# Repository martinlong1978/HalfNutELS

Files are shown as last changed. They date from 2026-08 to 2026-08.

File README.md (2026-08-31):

# HalfNutELS — Electronic Leadscrew

An open-source **Electronic Leadscrew (ELS)** controller for a metalworking lathe, running on an
**ESP32-WROOM-32E**, with a 320×240 LVGL TFT interface, a 3×3 keypad and a rotary encoder.

An electronic leadscrew replaces a lathe's mechanical change gears / gearbox. Instead of a train of
gears mechanically coupling the spindle to the leadscrew, an **encoder** on the spindle is read by
the microcontroller, which drives a **stepper motor** on the leadscrew in software-defined ratio to
the spindle. This lets you select any thread pitch or feed rate electronically — for single-point
threading and powered feeding — without swapping gears.

> **Note on the name:** *half-nuts* are the split nut a lathe operator clamps onto the leadscrew to
> engage a threading pass — and the part an electronic leadscrew makes redundant, since the pitch is
> now held in software rather than caught on a thread-dial line. The project was called *TeensyELS*
> until August 2026, after the Teensy it began on; Teensy support was removed well before the rename,
> and naming firmware after its microcontroller was a poor idea in the first place. The upstream
> project it derives from is still called TeensyELS — see [Attribution](#attribution). The KiCad
> projects and the board silkscreen also still carry the old name.

> **Note on the hardware:** the current design is the **LVGL board** in
> [`kicad/LVGL/`](kicad/LVGL/) (silkscreened `TeensyELS v0.6`, pre-rename) — an ESP32-WROOM-32E
> soldered directly to the board, driving a 320×240 SPI TFT through LVGL. It is the only board design
> in the repository — the earlier revisions have been removed.

---

## Contents
- [Features](#features)
- [Hardware / Components](#hardware--components)
- [Enclosure & keycaps](#enclosure--keycaps)
- [Getting boards made (PCB)](#getting-boards-made-pcb)
- [Building & flashing the firmware](#building--flashing-the-firmware)
- [Connecting & configuring](#connecting--configuring)
- [Operating the ELS — controls & display](#operating-the-els--controls--display)
- [Cutting a thread](#cutting-a-thread)
- [Firmware updates](#firmware-updates)
- [Settings reference](#settings-reference)
- [Diagnostics](#diagnostics)
- [Testing / development](#testing--development)
- [License](#license)
- [Attribution](#attribution)
- [Safety disclaimer](#safety-disclaimer)

---

## Features

- **Threading** — synchronise the leadscrew to the spindle at a selectable thread pitch for
  single-point threading. Metric (mm/rev) and imperial (TPI) thread pitch tables are built in.
- **Reverse threading** — a thread mode that runs the carriage in the opposite direction (from the
  left stop toward the right) for left-hand threads or threading away from a shoulder.
- **Feeding** — powered feed at a selectable feed rate (mm/rev metric, or thou/rev imperial).
- **Feed / thread mode switching** from the panel; **metric / imperial** from the menu.
- **Jog** — move the carriage left/right under power. Supports both an interactive "hold to jog"
  mode and a "jog to stop" mode.
- **End stops / stop positions** — set left and right stop positions so the carriage automatically
  decelerates and stops at a repeatable point (useful for threading up to a shoulder).
- **Thread sync** — the leadscrew tracks the spindle's angular position so a partially cut thread can
  be picked up again on the next pass.
- **Motion lockout** — while the carriage is under power the panel answers only **HALT** and
  **ENABLE**. There is no lock key to remember: the machine locks itself exactly when it matters.
  (This replaced an explicit button lock, which had to be unlocked at every power-on.)
- **DRO** — carriage position referenced to an endstop, with a travel bar that doubles as a readout.
- **Dark and light themes**, selectable on the device.
- **Web-based configuration** — all lathe parameters (encoder PPR, stepper PPR, gearbox ratio,
  leadscrew pitch, speeds, acceleration) plus WiFi credentials are configured over a built-in web
  page; settings are stored in the ESP32's non-volatile flash.
- **Over-the-air (OTA) firmware update** — pulls the latest [GitHub release](https://github.com/martinlong1978/HalfNutELS/releases)
  from a stable permalink and skips the download if the device is already on that version.
- **Motion-trace capture** — records ~25 s of following error, loop timing and spindle deltas and
  uploads it as CSV for offline analysis. Built to diagnose a threading glitch; kept because it is
  the fastest way to answer "is the fault in the maths or in the timing?".
- **On-device display** — a 240×320 ST7789 SPI TFT, driven in landscape (**320×240**) via **LVGL**,
  shows current mode, pitch, spindle RPM and status.
- **Rotary encoder** — turns to adjust whatever the panel currently has focused; its
  built-in LED shows the run state at a glance (the firmware drives the red and green channels,
  alternating them to flash a two-colour status).

---

## Hardware / Components

The controller is built around a custom PCB. KiCad design files, gerbers and fabrication outputs are
in the [`kicad/`](kicad/) directory.

**The current design is [`kicad/LVGL/`](kicad/LVGL/)** — silkscreened *TeensyELS v0.6*, a **4-layer**
board of roughly **113 × 109 mm**. It does not socket a dev-board module: the **ESP32-WROOM-32E is
soldered directly to the PCB**, the display is a separate SPI TFT module on a 14-pin socket, and the
board is designed to be **SMT-assembled** (JLCPCB) with only the connectors and the rotary encoder
hand-soldered.

### Bill of materials

**SMT parts** — taken from the JLCPCB production BOM
([`kicad/LVGL/jlcpcb/production_files/BOM-TeensyELS.csv`](kicad/LVGL/jlcpcb/production_files/BOM-TeensyELS.csv)),
cross-checked against the schematic:

| Designator(s) | Qty | Part / Value | Footprint | LCSC |
|---|---|---|---|---|
| U2 | 1 | **ESP32-WROOM-32E** — main controller (Wi-Fi module, 4 MB flash) | ESP32-WROOM-32D | C701342 |
| U1 | 1 | AMS1117-3.3 — 5 V → 3.3 V regulator | SOT-223-3 | C6186 |
| Q2–Q7, Q9 | 7 | BSS138 N-channel MOSFET (3.3 V ↔ 5 V level shifting, LED drive) | SOT-23 | C7420339 |
| C1 | 1 | 10 µF capacitor | 0805 | C15850 |
| C2 | 1 | 22 µF capacitor | 0805 | C45783 |
| C3, C4 | 2 | 0.1 µF capacitor | 0805 | C49678 |
| R1–R8, R11, R12, R17, R18, R20, R21 | 14 | 10 kΩ resistor (pull-ups) | 0805 | C17414 |
| R9, R10, R19 | 3 | 330 Ω resistor (encoder LED series) | 0805 | C17630 |
| R13, R14 | 2 | 0 Ω link (encoder direct-connect option) | 0805 | C17477 |
| SW1–SW10 | 10 | Omron B3FS-101xP **SMD** tactile switch (SW2–SW10 = the 3×3 keypad; SW1 = stepper-enable override) | SW_SPST_Omron_B3FS-101xP | C231324 |
| J5 | 1 | 2×3 1.27 mm header — UART programming header | PinHeader 2x03 1.27 mm SMD | C42372553 |

**Not fitted (DNP)** — an alternative encoder input path, see the note below:

| Designator(s) | Qty | Part / Value |
|---|---|---|
| Q1, Q8 | 2 | BSS138 (encoder level-shift MOSFETs) |
| R15, R16 | 2 | 1 kΩ (gate resistors for Q1/Q8) |

**Through-hole / hand-soldered parts** — these are *not* in the assembly BOM and must be fitted
yourself:

| Designator | Qty | Part | Purpose |
|---|---|---|---|
| J1 | 1 | Shielded RJ45 jack (RCH RC01937) | **Stepper driver** — step / dir / enable / alarm, at 5 V |
| J2 | 1 | JST-XH 4-pin vertical header (B4B-XH-A) | **Spindle encoder** — 5 V, GND, A, B |
| J3 | 1 | 1×14 2.54 mm socket | **Display module** (see below) |
| J4 | 1 | 2-pin 5.08 mm screw terminal (CUI TB007-508-02) | **5 V power input** |
| E1 | 1 | Illuminated (RGB) rotary encoder, SparkFun footprint | Pitch / jog-rate selection + status LED |

Not on the board at all, but **required to build a working ELS**:

- A **240×320 SPI TFT module** with the common **14-pin 2.54 mm header** (9 display pins + 5 touch
  pins). The firmware drives it as an **ST7789** and uses it in landscape, 320×240. Only the display
  pins are wired — the 5 touch pins are unconnected, and the backlight pin is tied to +3.3 V, so the
  backlight is permanently on and is *not* under software control.
- A **spindle encoder** — a quadrature encoder on the lathe spindle, wired to **J2** (not J1). The
  default configuration assumes **1200 PPR** (see [Settings reference](#settings-reference)).
- A **stepper motor + driver** for the leadscrew, wired to the RJ45 jack **J1**. The board provides
  step, dir and enable as 5 V open-drain outputs (10 kΩ pull-ups to +5 V) and accepts the driver's
  alarm output. The default configuration assumes a **400 step/rev** stepper.
- A **5 V supply** into J4 (which also feeds the encoder and the 3.3 V regulator), plus a suitable
  **power supply for the stepper driver** itself.
- A **USB-to-serial adapter** for flashing — the board has no USB connector, see
  [Building & flashing](#building--flashing-the-firmware).

> **Encoder input — 3.3 V vs 5 V.** J2's A/B pins can reach the ESP32 two ways: directly through the
> 0 Ω links **R13/R14**, or level-shifted through **Q1/Q8 + R15/R16**. The assembly BOM fits the 0 Ω
> links and leaves the MOSFET path off, i.e. it expects an encoder whose outputs are safe to feed
> straight into a 3.3 V GPIO. If your encoder swings to 5 V, fit Q1/Q8 and R15/R16 and leave R13/R14
> off. **Please verify against the schematic** ([`kicad/LVGL/TeensyELS.kicad_sch`](kicad/LVGL/TeensyELS.kicad_sch))
> before ordering.

### Connectors

| Ref | Type | Pinout |
|---|---|---|
| **J4** | 2-pin screw terminal | 1 = GND, 2 = **+5 V in** |
| **J2** | JST-XH 4-pin | 1 = +5 V, 2 = GND, 3 = encoder B, 4 = encoder A |
| **J1** | RJ45 (shielded) | 1 = ALARM (in), 3 = ENABLE, 5 = DIR, 7 = STEP; 2/4/6/8 = GND; shield = GND. All 5 V. |
| **J3** | 1×14 socket (display) | 14 = VCC, 13 = GND, 12 = CS, 11 = RESET, 10 = DC, 9 = MOSI, 8 = SCK, 7 = LED (tied to +3.3 V), 6 = MISO (not connected to the ESP32); 5–1 = touch pins, unconnected |
| **J5** | 2×3 1.27 mm | 1 = EN, 2 = +3.3 V, 3 = TXD, 4 = GND, 5 = RXD, 6 = BOOT (GPIO0) |
| **SW1** | on-board push button | Pulls the stepper **ENABLE** line to +5 V — a manual override, independent of the firmware |

### Pin assignments (ESP32)

Defined in [`lib/config/board.h`](lib/config/board.h) and matching the LVGL schematic:

| Function | GPIO |
|---|---|
| Spindle encoder A / B (J2) | 35 / 34 |
| UI rotary encoder A / B (E1) | 39 / 36 |
| Encoder status LED — red / green / blue (E1) | 22 / 21 / 12 |
| Leadscrew step | 25 |
| Leadscrew direction | 26 |
| Stepper enable | 17 |
| Stepper driver alarm input | 27 *(wired on the board; not read by the current firmware)* |
| Keypad matrix rows (H1/H2/H3) | 32 / 33 / 2 |
| Keypad matrix columns (V1/V2/V3) | 13 / 14 / 15 |
| TFT display (MOSI/SCLK/CS/DC/RST) | 19 / 18 / 5 / 16 / 23 |
| TFT backlight (`TFT_BL`) | 4 *(defined in the build flags but **not connected** on this board)* |
| Programming UART TXD / RXD (J5) | 1 / 3 |

> The A/B pins of both encoders are swapped in `board.h` relative to the schematic net names — that
> only sets which way round the counting goes, and is deliberate.

> **The keypad matrix is polled, not interrupt-driven.** A 2 ms task scans it and a host-tested
> debounce ([`lib/keyscan/`](lib/keyscan/)) turns the readings into press / click / hold / release
> events. Edge interrupts were tried and removed — see [`docs/keypad-audit.md`](docs/keypad-audit.md)
> for why they cannot be made reliable here.

---

## Enclosure & keycaps

Two 3D models are provided in [`cad/`](cad/), both as **STEP** files:

| File | What it is |
|---|---|
| [`cad/Keycaps.step`](cad/Keycaps.step) | Keycaps for the 3×3 keypad |
| [`cad/Enclosure.step`](cad/Enclosure.step) | A full enclosure for the controller |

STEP is a neutral CAD interchange format — it imports into FreeCAD, Fusion and SolidWorks, so the
models can be measured and edited before you make anything from them. To 3D-print a part, convert it
to **STL** or **3MF** in your CAD tool and slice that; the same STEP file can go to a machine shop if
you would rather have the enclosure cut than printed.

The keycaps cover the nine keys of the panel keypad — which legend belongs on which cap is set out in
[Keypad layout](#keypad-layout), along with the warning to re-confirm the scan codes before making
caps if you have rewired the loom. For reference when checking fit, the board itself is roughly
**113 × 109 mm**.

> No print settings, material or fastener sizes are specified with these models. Check them against
> your own printer and hardware before committing to a run.

---

## Getting boards made (PCB)

Fabrication outputs for the LVGL board are pre-generated under [`kicad/LVGL/`](kicad/LVGL/). The
JLCPCB set in [`kicad/LVGL/jlcpcb/production_files/`](kicad/LVGL/jlcpcb/production_files/) is the one
to use — it is the only output that carries **LCSC part numbers**, and its BOM matches the assembly
intent (SMT parts only, encoder level-shift path left off).

> ⚠️ **Do not use `kicad/LVGL/production/bom.csv` or `positions.csv`.** Those files are stale
> carry-overs from an earlier board revision — they still list a socketed display module and a Teensy
> footprint, neither of which exists on this board. Regenerate them from KiCad if you need them.

### Option A — JLCPCB (bare board, or with assembly)

1. Go to [jlcpcb.com](https://jlcpcb.com) and click **Add gerber file**.
2. Upload [`kicad/LVGL/jlcpcb/production_files/GERBER-TeensyELS.zip`](kicad/LVGL/jlcpcb/production_files/GERBER-TeensyELS.zip)
   (do **not** unzip it — upload the zip directly). The KiCad-native export
   [`kicad/LVGL/gerbers.zip`](kicad/LVGL/gerbers.zip) is equivalent if you prefer it.
3. Confirm the auto-detected settings: **Layers = 4**, and the board dimensions shown in the preview
   (≈113 × 109 mm). Choose thickness, colour, surface finish, etc. as desired.
4. *(Optional — assembly / PCBA)* Enable **PCB Assembly** (top side only), then upload:
   - **BOM:** [`kicad/LVGL/jlcpcb/production_files/BOM-TeensyELS.csv`](kicad/LVGL/jlcpcb/production_files/BOM-TeensyELS.csv)
   - **Pick-and-place / CPL:** [`kicad/LVGL/jlcpcb/production_files/CPL-TeensyELS.csv`](kicad/LVGL/jlcpcb/production_files/CPL-TeensyELS.csv)
5. Review the placement in JLCPCB's assembly preview — pay particular attention to the orientation of
   U1, U2 and the MOSFETs — resolve any part substitutions, and place the order.
6. Hand-solder the through-hole parts afterwards: **J1, J2, J3, J4 and the rotary encoder E1**.

### Option B — PCBWay

1. Go to [pcbway.com](https://www.pcbway.com) and choose **Quick-order PCB → Add Gerber File**.
2. Upload [`kicad/LVGL/gerbers.zip`](kicad/LVGL/gerbers.zip).
3. Confirm layer count (**4**) and dimensions, pick your board options, and add to cart.
4. *(Optional — assembly)* Choose **Turnkey Assembly** and provide the BOM and pick-and-place files
   above. PCBWay does not use LCSC numbers directly, so expect to confirm equivalents for each line.

---

## Building & flashing the firmware

The firmware is a [PlatformIO](https://platformio.org/) project (see
[`platformio.ini`](platformio.ini)).

### 1. Install PlatformIO

Install the [PlatformIO IDE extension for VS Code](https://platformio.org/install/ide?install=vscode),
or the [PlatformIO Core CLI](https://docs.platformio.org/en/latest/core/installation/index.html).
PlatformIO will automatically download the ESP32 toolchain and the libraries listed in
`platformio.ini` on first build.

### 2. Connect a USB-to-serial adapter

The LVGL board has **no USB connector** — the ESP32-WROOM-32E is programmed through the 2×3 1.27 mm
header **J5**:

| J5 pin | Signal | Adapter |
|---|---|---|
| 1 | EN (reset) | RTS *(optional — for auto-reset)* |
| 2 | +3.3 V | — *(do not back-feed if the board is powered from J4)* |
| 3 | TXD (ESP32 → adapter) | RX |
| 4 | GND | GND |
| 5 | RXD (adapter → ESP32) | TX |
| 6 | BOOT (GPIO0) | DTR *(optional — for auto-bootloader)* |

Use a **3.3 V** adapter. If you only wire TX/RX/GND, you must put the module into the bootloader by
hand — hold GPIO0 low, pulse EN low and release it, then start the upload.

### 3. Build & upload

There are two ESP32 build environments:

- **`esp32dev_usb`** — build and flash over the serial adapter. This is the environment to use for
  normal development. Edit the `upload_port` in `platformio.ini` (default `COM14`) to match the port
  your adapter enumerates as.

  ```sh
  pio run -e esp32dev_usb -t upload
  ```

- **`esp32dev_publish`** — a release build that uses a custom upload command (`publish.cmd`) for
  producing/publishing an OTA image rather than a direct flash.

  ```sh
  pio run -e esp32dev_publish
  ```

Both ESP32 environments still declare `board = lilygo-t-display`. That is just a convenient 4 MB
ESP32-D0WD profile and is compatible with the WROOM-32E module — the display geometry that matters is
set explicitly in the build flags (`TFT_WIDTH=240`, `TFT_HEIGHT=320`, ST7789 driver, SPI pins), and a
custom 4 MB partition table (`my_4MB.csv`) is used.

---

## Connecting & configuring

Configuration is done over WiFi through a built-in web page — there is no need to recompile to
retune the firmware for your lathe.

1. **Enter configuration mode.** The device starts a WiFi **Access Point** on first boot (when no
   valid settings are stored yet), whenever you **hold `OK` — the centre key — while powering on**,
   or from the **Wi-Fi setup** menu tile. See [`src/main.cpp`](src/main.cpp).
   - AP SSID: **`ELS_Wifi`**
   - AP password: **`123456789`**
2. **Connect** your phone or laptop to that access point. The SSID, password and IP address are shown
   on the device's display, along with a QR code for the WiFi credentials.
3. **Open the device in a browser.** The firmware runs a **captive portal** — a catch-all DNS server
   plus the usual Android/Apple/Windows detection URLs — so most phones will pop the configuration
   page up automatically on connecting. If yours doesn't, browse to the IP shown on the display
   (typically `192.168.4.1`) to reach the *ELS Setup* page.

| First-run setup screen | Connected |
|---|---|
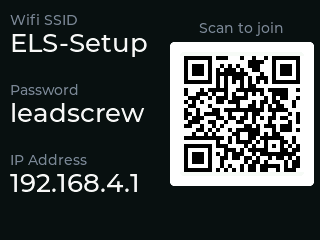
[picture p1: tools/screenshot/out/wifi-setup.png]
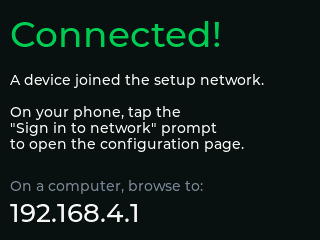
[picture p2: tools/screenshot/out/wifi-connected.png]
|  |  |

4. **Fill in the settings** (see [Settings reference](#settings-reference)) and press **Submit**.
   Settings are written to the ESP32's flash. Press **Reset** on the page (or power-cycle) to reboot
   into normal operation with the new settings.

---

## Operating the ELS — controls & display

The panel is nine keys and a rotary encoder. Everything below is driven from those.

> Every screenshot in this README is rendered from the **real display code** on a host machine
> (`bash tools/screenshot/render.sh`), so what you see here is what the panel draws.

### Power-on

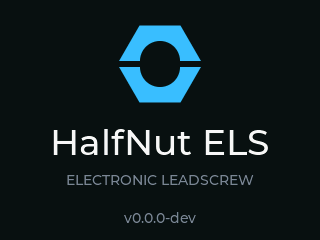
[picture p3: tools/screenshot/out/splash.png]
Boot splash


The splash holds for **two seconds** on every normal boot, then the rest screen replaces it. It
carries the running **firmware version**, which is the quickest way to check what a machine is on
without opening the menu — worth a glance after an over-the-air update. It is drawn on whichever
theme is stored, and it is skipped entirely on the first-run setup path, where the Wi-Fi credentials
matter more than the branding.

### The rest screen

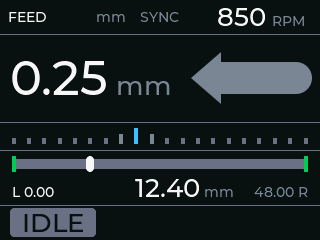
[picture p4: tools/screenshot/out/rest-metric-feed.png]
Rest screen, metric feed


Top row: **mode**, **units**, **sync state**, **spindle RPM**. The large figure is the current pitch
or feed rate. Below it the **travel bar** shows the carriage between the endstops — it doubles as a
DRO readout. The chip at the bottom left is the **machine state** (`IDLE`, `FEED`, `THREAD`, `JOG`).

| Metric thread | Imperial feed | Spindle running backwards |
|---|---|---|
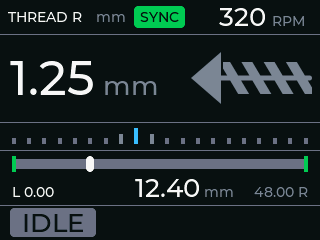
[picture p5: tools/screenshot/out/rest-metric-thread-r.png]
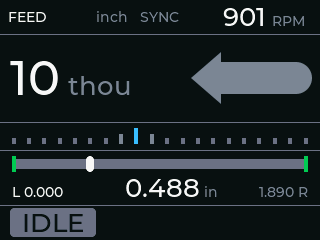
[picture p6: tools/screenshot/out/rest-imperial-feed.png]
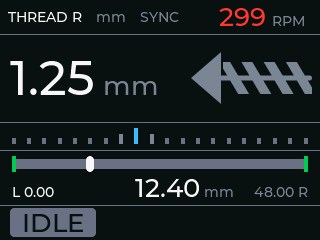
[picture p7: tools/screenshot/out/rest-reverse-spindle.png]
|  |  |  |

### Keypad layout

Selectors along the top, the two actuators plus `OK` in the middle where your thumbs sit, and
machine state along the bottom:

Mk2 keypad layout

| | Left | Centre | Right |
|---|---|---|---|
| **Top row** | `MODE` | `RATE` | `STOPS` |
| **Middle row** | `◀` | `OK` | `▶` |
| **Bottom row** | `HALT` | `MENU` | `ENABLE` |

The small numbers on the diagram are the **matrix scan codes** — useful when wiring a panel or
reading a debug trace. They are `code = H | V << 3`, with the H rows on GPIO 32 / 33 / 2 and the V
columns on GPIO 13 / 14 / 15; the mapping is defined in [`lib/config/board.h`](lib/config/board.h).
If you rewire the loom the nine codes stay distinct but the assignment transposes, so re-confirm by
pressing each key and reading its code before making new caps.

The three top keys choose **what the arrows drive**; the arrows are the only actuators. That is the
*focus model*: press a selector, a panel opens, the arrows adjust it, `OK` commits. Focus returns to
jog on its own after 4 seconds.

*(Holding `OK` during power-on boots into Wi-Fi configuration mode.)*

### Arrows at rest — jog

With nothing else focused the arrows move the carriage, and what they do depends on whether that
side has a stop set — the machine already knows which behaviour you mean:

| | Stop **set** on that side | Stop **unset** |
|---|---|---|
| **Click** | Run under power to the stop, then hold | — |
| **Hold** | (same as click) | Jog continuously while held; decelerate on release |

A second press of the same arrow during a powered run **cancels** it.

### Key reference

| Control | Click | Hold |
|---|---|---|
| `MODE` | Open the mode picker — Feed / Thread R / Thread L | — |
| `RATE` | Open the pitch picker | — |
| `STOPS` | Open the stops panel | Clear **both** stops, after a 1 s confirm |
| `◀` / `▶` | Jog, or run to the stop (see above) | Continuous jog when no stop is set |
| `OK` | Jog-speed picker (at rest); commit and close (in a picker) | **Zero the DRO** here |
| `MENU` | Open the menu carousel; press again to close | — |
| `HALT` | Decelerate to a stop. **Always live**, from any screen | — |
| `ENABLE` | Engage / disengage the leadscrew | — |
| Encoder | Adjust whatever is focused (pitch at rest) | — |

Pressing the **same selector twice** closes its panel again — `MODE`, `RATE`, `STOPS` and `MENU` all
toggle.

**`ENABLE` takes two presses when a panel is open**: the first dismisses the panel, the second
engages. Engaging is a commitment to cut, and it should not happen while a picker is covering the
state chip.

### The selector panels

| `MODE` | `RATE` | `OK` — jog speed |
|---|---|---|
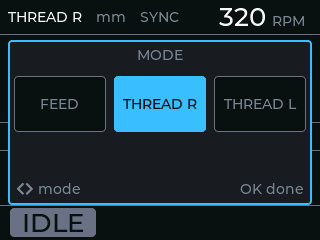
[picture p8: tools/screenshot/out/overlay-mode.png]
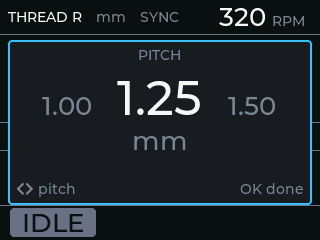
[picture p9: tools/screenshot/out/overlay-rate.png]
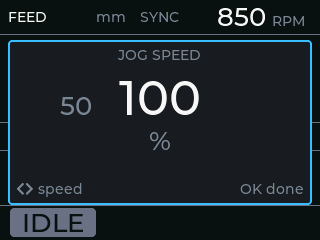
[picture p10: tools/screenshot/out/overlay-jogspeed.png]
|  |  |  |

**Stops.** The panel shows the travel bar full width with both markers and the live position.
Setting a stop is cheap to undo; clearing one loses a position you may have spent time finding, so
the two gestures are deliberately asymmetric:

| Gesture | Effect |
|---|---|
| `◀` click, left stop unset | Set the left stop **here** |
| `◀` click, left stop set | Prompts "hold to clear" — no action |
| `◀` hold, left stop set | Clear the left stop |
| `STOPS` hold | Clear **both**, after a 1 s confirm bar |

`▶` is the mirror.

| Stops panel | Clearing both — confirm bar filling |
|---|---|
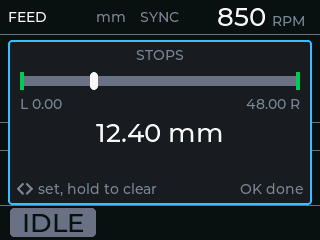
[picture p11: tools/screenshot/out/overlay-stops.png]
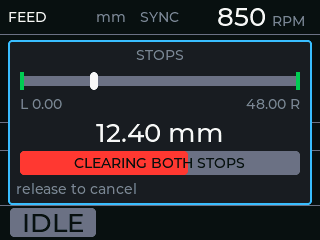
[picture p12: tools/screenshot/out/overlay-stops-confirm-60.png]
|  |  |

### The menu

`MENU` opens a horizontal carousel; the arrows move between tiles and `OK` activates. The carousel
**wraps**, so the far end is one press away in the other direction. Tiles never edit in place — `OK`
either performs a one-shot action or opens the matching panel.

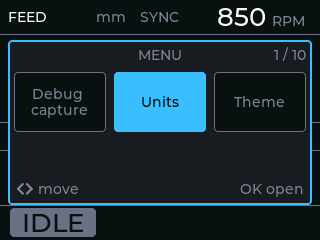
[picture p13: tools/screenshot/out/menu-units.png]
Menu carousel


| Tile | `OK` does |
|---|---|
| **Units** | Toggle mm / inch |
| **Theme** | Toggle dark / light (persisted) |
| **DRO datum** | Choose which endstop is zero (persisted) |
| **Jog speed** | Open the jog-speed picker |
| **Sync** | Set a thread sync point at the current spindle angle and carriage position |
| **Software update** | Check for and install a new firmware release |
| **Wi-Fi setup** | Reboot into the configuration access point |
| **Diagnostics** | Live following error, spindle vs leadscrew rates, sync anchor |
| **About** | Firmware version, IP address, uptime |
| **Debug capture** | Arm a motion-trace capture |

A tile that cannot act right now renders as **UNAVAILABLE** with the reason on the hint row, rather
than vanishing — so the tile numbering never shifts under you:

| Sync, outside a thread mode | Update, while the carriage is moving |
|---|---|
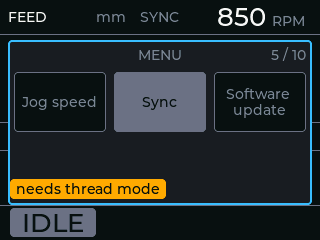
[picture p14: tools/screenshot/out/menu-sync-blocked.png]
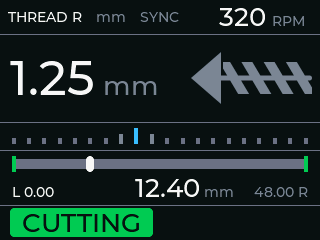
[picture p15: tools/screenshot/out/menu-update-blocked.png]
|  |  |

### The DRO

A position is meaningless without a zero, and "wherever the machine happened to boot" is the worst
available choice — so **zero is referenced to an endstop**. First match wins:

| # | Condition | Datum |
|---|---|---|
| 1 | Manual zero set (`OK` held) | That position, tagged `MAN` |
| 2 | Both stops set | The one chosen on the **DRO datum** tile |
| 3 | Exactly one stop set | That one — the preference cannot be honoured |
| 4 | Neither stop set | Power-on origin, flagged `REL` |

Position increases to the **right**, so a right-hand datum counts negative leftward — ordinary DRO
behaviour. The readout flashes for about a second whenever the datum moves, because setting a second
stop can hand zero to the other end and the numbers will jump.

| DRO datum picker | Refused while under power |
|---|---|
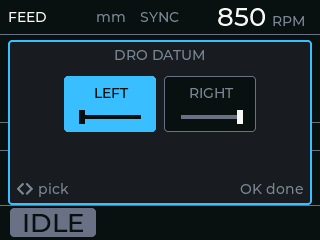
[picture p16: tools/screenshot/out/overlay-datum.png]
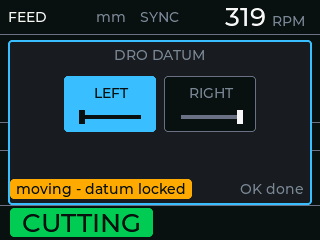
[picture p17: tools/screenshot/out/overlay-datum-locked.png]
|  |  |

### While the carriage is moving

The panel answers **only `HALT` and `ENABLE`**. No menus, no pickers, no settings — and any open
panel closes itself when motion starts. Your attention belongs on the tool and the work, not the
screen. `HALT` is the reflex; `ENABLE` is the deliberate one.

The one exception is **Diagnostics**, which stays up through jogging and cutting because watching it
while the machine runs is the entire point. `OK` clears it.

| Jogging | Cutting | Decelerating |
|---|---|---|
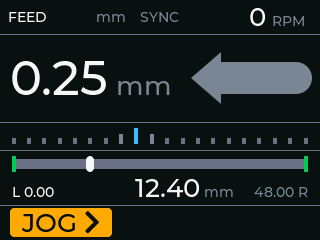
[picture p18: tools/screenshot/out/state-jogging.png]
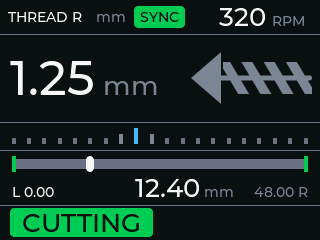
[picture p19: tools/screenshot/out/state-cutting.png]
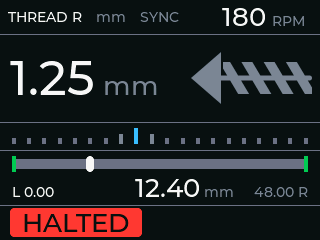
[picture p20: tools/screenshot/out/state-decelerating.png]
|  |  |  |

---

## Cutting a thread

1. **Set the mode.** `MODE`, arrows to **Thread R** (or **Thread L** for a left-hand thread), `OK`.
2. **Set the pitch.** `RATE`, arrows to your pitch, `OK`. The **Units** tile switches between metric
   and TPI; the controller remembers a pitch per mode-and-unit pair, so switching back and forth
   does not lose your place.
3. **Set the stops.** Jog to where the thread should end — usually just short of the shoulder — press
   `STOPS`, then `◀` or `▶` to set that stop. Do the same at the starting end. The carriage now
   decelerates and stops there on every pass, which is what makes threading to a shoulder
   repeatable.
4. **Return to the start** and take your first depth of cut on the cross-slide.
5. **Press `ENABLE`.** The leadscrew waits for the spindle to come round to the sync point, then
   tracks the thread to the far stop and stops.
6. **Retract, return the carriage, advance the depth, `ENABLE` again.** The sync point is preserved,
   so every pass follows the same helix.

**Picking up an existing thread.** Stop the spindle, hand-position the tool so it sits in an existing
groove, then use the **Sync** menu tile. That declares "this spindle angle and this carriage position
are in sync", and every later engagement re-enters that same helix instead of ploughing a new groove
across it. The **Diagnostics** screen shows which anchor is currently in use.

### Feeding

Same flow, simpler: `MODE` → **Feed**, `RATE` → your feed rate (mm/rev, or thou/rev in imperial), set
a stop if you want the cut to end somewhere repeatable, then `ENABLE`.

---

## Firmware updates

**From the device.** `MENU` → **Software update** → `OK`. The controller checks the latest
[GitHub release](https://github.com/martinlong1978/HalfNutELS/releases), tells you if you are already
on it, and otherwise downloads and flashes, showing progress on screen. It uses the Wi-Fi credentials
from the setup page.

| Checking | Already current | Downloading |
|---|---|---|
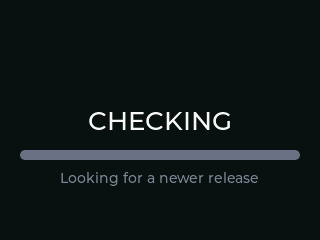
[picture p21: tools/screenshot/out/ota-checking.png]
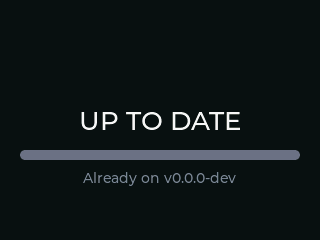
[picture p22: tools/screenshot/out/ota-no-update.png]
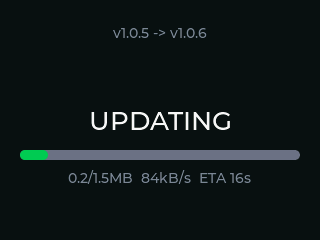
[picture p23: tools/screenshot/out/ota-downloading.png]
|  |  |  |

**Over USB.** `pio run -e esp32dev_usb -t upload`, via the J5 serial header.

**Publishing your own.** Bump `FIRMWARE_VERSION` in [`include/version.h`](include/version.h), then
`pio run -e esp32dev_publish` and `bash scripts/release.sh` (needs the `gh` CLI). The OTA permalink
resolves to whatever is marked *latest*, so publish full releases rather than drafts.

---

## Settings reference

Settings come in two kinds, and the split is deliberate.

**Lathe geometry is web-only.** Encoder PPR, stepper PPR, direction, gearbox ratio, leadscrew pitch,
jog speed, acceleration and max speed are *commissioning* values: set once over Wi-Fi with the lathe
offline, and changed only there. The device never writes them. Getting one wrong turns every
subsequent cut into scrap, so they are deliberately not reachable from a panel you might brush past
mid-job.

**Preferences are on-device.** Theme and DRO datum are the things worth changing mid-session, and
they live on the menu. Saving them is refused while the carriage is under power.

### Wi-Fi / update settings

| Web label | Field | Meaning |
|---|---|---|
| **Wi-Fi network** | `ssid` | Network the device joins for OTA updates and trace uploads. Up to 31 chars. |
| **Wi-Fi password** | `password` | Up to 62 chars. Leave blank for an open network. |
| **Firmware update URL** | `url` | Where **Software update** pulls from. Defaults to this repo's `latest` release permalink. |
| **Debug capture URL** | `debugUrl` | Where the **Debug capture** tile POSTs its motion trace. Blank disables sending. See [`tools/debugsink/`](tools/debugsink/). |

### Lathe geometry

Defaults are in [`lib/config/latheconfig.h`](lib/config/latheconfig.h).

| Web label | Field | Default | Units | Meaning |
|---|---|---|---|---|
| **Spindle encoder** | `spindleEncoderPpr` | `1200` | pulses/rev | Pulses per spindle revolution. Must match your encoder or every pitch is wrong. |
| **Stepper** | `stepperPpr` | `400` | steps/rev | Steps per stepper revolution — full steps × the microstepping set on the driver. |
| **Invert motor direction** | `invertDirection` | `true` | boolean | Flips the direction sense so left and right match your lathe. |
| **Gearbox ratio** | `gearboxRatioNumerator` / `gearboxRatioDenominator` | `2` / `1` | ratio | Any mechanical reduction between stepper and leadscrew. Effective ratio = numerator ÷ denominator. |
| **Leadscrew pitch** | `leadscrewPitchMm` | `2.54` | mm/rev | Carriage travel per leadscrew revolution. |
| **Jog speed** | `jogSpeed` | `40` | mm/s | Full-speed jog. The on-device jog-speed picker selects a percentage of this. |
| **Acceleration** | `leadscrewAcceleration` | `150` | mm/s² | Ramp used for all leadscrew motion. |
| **Max speed** | `leadscrewMaxSpeed` | `40` | mm/s | Upper limit for leadscrew motion. |

Steps/mm, pulses/sec and the pulse timings are derived from these once at startup
([`lib/config/latheconfig.cpp`](lib/config/latheconfig.cpp)); the metric and imperial pitch tables
are in [`lib/config/config.h`](lib/config/config.h).

### On-device preferences

| Setting | Where | Options |
|---|---|---|
| **Units** | `MENU` → Units | mm / inch |
| **Theme** | `MENU` → Theme | Dark / light — persisted |
| **DRO datum** | `MENU` → DRO datum | Which endstop is zero when both are set — persisted |
| **Jog speed** | `OK` at rest, or `MENU` → Jog speed | 1 %, 5 %, 10 %, 25 %, 50 %, 100 % of the configured jog speed |

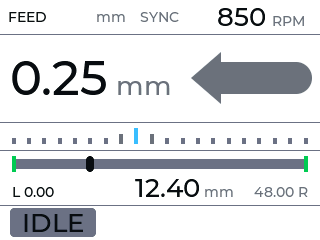
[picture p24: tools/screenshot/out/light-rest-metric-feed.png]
Light theme


*The light theme. Both are designed for the panel rather than inverted from each other.*

### Where settings live, and how to wipe them

Settings are stored as a raw struct in flash, guarded by a validity sentinel (`CHECKVALUE` in
[`lib/config/latheconfig.h`](lib/config/latheconfig.h)). If the stored value does not match the
firmware's, the whole blob is discarded and the device boots into first-run AP setup — which is how
a firmware change that moves the layout avoids reading someone else's bytes as your geometry.

To clear everything deliberately — including Wi-Fi credentials — use **Factory reset** at the bottom
of the web setup page. It asks for confirmation, then reboots into first-run setup.

---

## Diagnostics

`MENU` → **Diagnostics** shows live following error, spindle and leadscrew rates, and which sync
anchor the helix is currently pinned to. Unlike every other screen it **stays up while the machine
runs**, because that is when its numbers mean anything — at rest they are all zero. `OK` clears it.

| Diagnostics | Following error | Manual sync anchor |
|---|---|---|
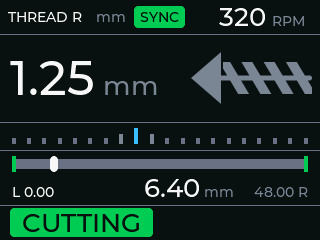
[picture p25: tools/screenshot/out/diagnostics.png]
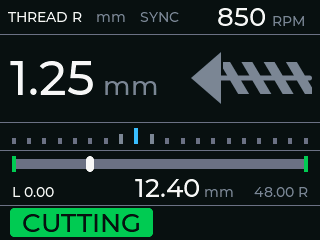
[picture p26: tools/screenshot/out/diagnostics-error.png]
|  |  |  |

**Motion-trace capture.** `MENU` → **Debug capture** arms a recorder that samples following error,
loop timing and spindle deltas at 40 Hz for about 25 seconds, then uploads it as CSV to the
**Debug capture URL** once the carriage is at rest. [`tools/debugsink/`](tools/debugsink/) has a
stdlib-only Python receiver, a PHP drop-in and an analysis script that flags direction reversals and
correlates error spikes against loop stalls — which is what distinguishes "the maths is wrong" from
"the loop is being starved".

---

## Testing / development

The motion/business logic is designed to be unit-testable on your host machine without any hardware,
using the **`native`** PlatformIO environment (the project's default env), which builds against
GoogleTest/GMock:

```sh
pio test -e native
```

The suite is 455 cases and covers the parts where a mistake is expensive: the UI focus state machine,
the keypad debounce and gesture recognition, DRO datum resolution, thread-sync anchoring, stop
handling, the config layout in flash, and the trace capture. Motion tests drive a virtual clock so a
spindle can be turned at a chosen rate without hardware.

### Seeing the screens without a lathe

```sh
bash tools/screenshot/render.sh
```

Renders the **real** `Display` class on the host and writes one 320×240 PNG per scenario to
`tools/screenshot/out/` — every screenshot in this README came from it. Only `Arduino.h`, `SPI.h` and
`TFT_eSPI.h` are shimmed; the display, DRO, UI state and LVGL build are the production code, against
the project's own `lv_conf.h`. Scenes drive it through the same public inputs the firmware does, so a
screen the keypad cannot reach cannot be screenshotted either.

`native` is built with `-D PIO_UNIT_TESTING=1`, which selects host test doubles in place of the
ESP32 hardware classes. See the [`test/`](test/) directory for the test suites.

---

## License

This project is licensed under the **GNU General Public License v3.0**. See the [`LICENSE`](LICENSE)
file for the full text.

You are free to use, study, share and modify this software under the terms of the GPLv3. Derivative
works and distributed modified versions must also be made available under the GPLv3.

---

## Attribution

This firmware is **derived from the "TeensyELS" project by NoEngineerHere** (associated with the
*Not an Engineer* YouTube channel), with thanks to the upstream author for the original work this
builds on:

- **Upstream repository:** https://github.com/NoEngineerHere/TeensyELS

The derivation is evidenced by this repository's original name (*TeensyELS*, matching upstream, until
the August 2026 rename to *HalfNutELS*), the near-verbatim original `README.md` stub, a shared project
structure (PlatformIO project, `native` GoogleTest environment, `kicad/` hardware directory), and this
repo's history migrating from Teensy to ESP32 (Teensy support removed in commit `cbd1b22`).

**Licensing:** the project owner has confirmed that release under the GPLv3 is cleared.

> A separate, well-known project — **Clough42 "electronic-leadscrew"** by James Clough
> (https://github.com/clough42/electronic-leadscrew) — is a *different* ELS design (TI F280049C
> microcontroller, MIT-licensed) and is **not** the upstream of this code; it is noted only to avoid
> confusion with the best-known open ELS project.

---

## Safety disclaimer

**This project controls moving machinery and is provided with no warranty of any kind.**

A lathe with a powered leadscrew can cause **serious injury or death** and can destroy tooling and
workpieces. An electronic leadscrew removes the mechanical safeguards of change gears — a software
bug, miswired encoder, wrong setting, or loss of spindle sync can drive the carriage unexpectedly,
including into the chuck.

- Use at your **own risk**. You are responsible for the safe design, wiring, configuration and
  operation of your machine.
- **Test thoroughly with the spindle stopped and, where possible, the leadscrew disconnected** before
  cutting.
- Always know where your **stop positions** and emergency stop are before engaging.
- This firmware is **experimental** and, as noted above, may contain bugs affecting speed and
  acceleration limits.

As stated in the GPLv3, this software is distributed in the hope that it will be useful, but
**WITHOUT ANY WARRANTY**; without even the implied warranty of MERCHANTABILITY or FITNESS FOR A
PARTICULAR PURPOSE.

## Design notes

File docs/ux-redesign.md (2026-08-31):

# UX redesign — button panel and on-screen UI

Status: **design proposal**, branch `ux-redesign`. Nothing here is implemented yet.

Goal: collapse nine top-level buttons down to a small set of first-class controls plus a
menu, and give the screen a coherent visual language. The panel stays a 3×3 matrix — only
the cap legends and the `board.h` `#define`s change.

---

## 1. The core idea: a focus model

Today every button is a verb. Nine verbs is too many, and the two most valuable keys
(left/right) are locked to a single verb each.

The redesign makes **◀ / ▶ the only actuators**, and the other keys choose *what the arrows
act on*. That one change is what buys back the panel.

> **Focus** is the field the arrows currently drive. It rests on **JOG** and returns there
> automatically.

| Focus | ◀ / ▶ do | Entered by | Leaves on |
|---|---|---|---|
| **JOG** (rest) | Move the carriage | default | — |
| **JOG SPEED** | Step the jog speed | `OK` | `OK`, `HALT`, 4 s idle |
| **RATE** | Step the pitch list | `RATE` | `OK`, `HALT`, 4 s idle |
| **MODE** | Cycle feed / thread-R / thread-L | `MODE` | `OK`, `HALT`, 4 s idle |
| **STOPS** | Set / clear the left / right stop | `STOPS` | `OK`, `HALT`, 4 s idle |
| **MENU** | Move through menu tiles | `MENU` | `MENU`, `HALT` |

### The rotary encoder

The encoder drives **whatever has focus**, with one deliberate exception:

| Focus | Encoder does |
|---|---|
| **Jog** (rest) | **Pitch** — *not* what the arrows do at rest. The encoder fills the gap, so pitch is adjustable without pressing `RATE` first. |
| Rate | Pitch |
| Jog speed | Jog speed |
| Mode | Mode |
| Menu | Move between tiles |
| **Stops** | **Inert.** A knob is far easier to nudge than a key, and committing an endstop position must stay a deliberate keypress. |

It routes through `UiState` like every key, so it obeys the same focus rules and the same
engaged-inhibit. It previously called `next/prevFeedPitch()` directly, bypassing all of it.

### ENABLE takes two presses when a widget is open

Engaging is a commitment to cut, and you should not commit while your attention is still inside
a picker. So with any widget or the menu open, the first `ENABLE` press **only dismisses it**;
a second press engages. At rest it engages immediately, as before.

`OK` has three jobs, and they never overlap:

| Gesture | Context | Effect |
|---|---|---|
| Click | Widget open | Done — commit and dismiss |
| Click | At rest | Open jog speed — the setting for what the arrows already drive |
| **Hold** | At rest | **Zero the DRO here** (§8) |

It is the only key that would otherwise sit idle at rest.

The focused field is always outlined in the accent colour and carries `◀ ▶` chevrons, so
"what will the arrows do right now" is answerable at a glance without pressing anything.

---

## 2. Panel layout

```
┌──────────┬──────────┬──────────┐
│   MODE   │   RATE   │  STOPS   │   selectors — choose what ◀ ▶ drive
├──────────┼──────────┼──────────┤
│    ◀     │    OK    │    ▶     │   the only actuators
├──────────┼──────────┼──────────┤
│   HALT   │   MENU   │  ENABLE  │   machine state
└──────────┴──────────┴──────────┘
```

Three rows with three distinct jobs. Selectors on top, actuators in the middle where the
thumbs sit, state on the bottom.

### Matrix mapping

The scan builds `code = a | b<<3` (`keyarray.cpp:125,137-138`) where `a` is the H bitmask
and `b` the V bitmask. **Physical rows run along H, physical columns along V** — so the
codes read down the H index and across the V index:

| | V1 (left) | V2 (centre) | V3 (right) |
|---|---|---|---|
| **H1** (top) | `9` | `17` | `33` |
| **H2** (mid) | `10` | `18` | `34` |
| **H3** (bot) | `12` | `20` | `36` |

Today's caps sit on those codes like this — note Rate−/Rate+ adjacent on the top row and
Jog L/R adjacent on the bottom, the grouping this redesign breaks up:

| | V1 | V2 | V3 |
|---|----|----|----|
| **H1** | `9` Rate − | `17` Rate + | `33` Mode |
| **H2** | `10` Sync | `18` Half-nut | `34` Enable |
| **H3** | `12` Lock | `20` Jog ◀ | `36` Jog ▶ |

The Mk2 assignment is a pure `board.h` edit:

| | V1 | V2 | V3 |
|---|----|----|----|
| **H1** | `9` MODE | `17` RATE | `33` STOPS |
| **H2** | `10` ◀ | `18` OK | `34` ▶ |
| **H3** | `12` HALT | `20` MENU | `36` ENABLE |

Note `18` stays the centre key in both layouts, and it is today's `ELS_HALF_NUT_BUTTON` —
the key sampled at boot for setup mode (`main.cpp:120-129`). Putting **OK** there keeps the
boot gesture memorable: *hold OK at power-on for setup*.

### What happened to the old nine

| Old key | Fate |
|---|---|
| Rate increase / decrease | → `RATE` + arrows (one key freed) |
| Jog left / right | → bare arrows (one key freed) |
| Mode cycle | → `MODE` (unchanged, now opens a widget) |
| Enable | → `ENABLE` (unchanged) |
| Lock | **removed** — see §7 |
| Thread sync | → menu tile (its short-click was never implemented) |
| Half-nut | → `OK`; its OTA hold moves to a menu tile, its debug click is deleted |
| — | new: `STOPS`, `HALT`, `MENU` |

---

## 3. Arrows at rest — jog

With focus on JOG, the arrows are context-sensitive on whether that side has a stop:

| ◀ pressed | Left stop `SET` | Left stop `UNSET` |
|---|---|---|
| Click | Run under power to the left stop, then hold position | — |
| Hold | Jog while held at the selected manual jog speed, arresting at the left stop; decelerate in place on release | Continuous jog while held; decelerate on release |

▶ is the mirror. This unifies the two jog behaviours that today are split across a mode
(`FM_JOG` hold-to-move vs. non-jog click-to-stop) — the machine already knows which one you
mean, because it knows whether the stop exists.

The two gestures cannot collide: the keypad never emits a `Click` after a `Hold`
(`lib/keyscan`), so one press is either a run or a jog and never both.

**There are now two hold thresholds.** A press becomes a `Hold` at **500 ms**
(`kKeyHoldMs`), halved because on an arrow the wait is dead time before the carriage
moves and firing early costs at worst a jog that stops the moment you let go. Every
gesture that **takes something away** fires on `LongHold` at **1 s** instead
(`kKeyLongHoldMs`) and so kept the dwell it already had: clear both stops, clear one
stop, and zero the DRO. A press released between the two does nothing at all, which is
what keeps letting go the escape hatch the confirm bar offers.
So in the STOPS widget: a tap sets a stop, past 500 ms it is a hold and the tap is
cancelled, and only at 1 s - with the bar full - does the clear fire.

Hold on a side with a stop is a **jog**, not a shorter way to say click. Releasing the arrow
decelerates the carriage where it is rather than letting it carry on to the stop, and the
speed is the operator's — `jogSpeedPps() * getJogSpeed()`, the same speed the stop-free jog
in the right-hand column runs at, not the click-run's fixed `jogSpeedPps()`. The multiplier
is the control the operator has for how fast a held jog moves; a jog that ignored it would
not be the feature.

Consequences:

- **`FM_JOG` disappears from the mode cycle.** `IncFeedMode()` becomes
  `FEED → THREAD → THREAD_REVERSE → FEED`. Jog is always available, never a mode.
- A second press of the same arrow during a powered run **cancels** it (today's
  `MM_DECELLERATE` behaviour, kept).
- Arrows are **inhibited while `MM_ENABLED`**. The state bar says why rather than silently
  ignoring the press.
- **Holding an arrow is no longer the escape from a misplaced stop on that side.** The
  dead-man jog (`MM_INTERACTIVE_JOG_*`) drives straight through a stop, and on a side with a
  stop set the hold now reaches `MM_HOLD_JOG_*` instead, which arrests at it. The remaining
  route off a stop that is in the wrong place is to **unset it first** — a hold on that arrow
  with `STOPS` open (§4) — which is permitted at rest, since stop edits are inhibited only
  under power. A real behaviour change, and arguably the safer one: the gesture it replaces
  drove a carriage through a limit towards the chuck.
- **Jog speed moves onto `OK`.** Today it rides on `next/prevFeedPitch()`, which dispatch to
  `inc/decJogSpeed()` only when the mode is `FM_JOG` (`globalstate.cpp:158-176`). With that
  mode gone it needs an explicit home: tap `OK` at rest, arrows step the speed, `OK` again
  returns. It keeps a menu tile as the discoverable route.
- While the jog-speed widget is open the arrows own the speed, not the carriage — so jogging
  pauses for as long as it is up. It is a two-tap in-and-out, not somewhere you linger.

---

## 4. The selector widgets

All three share one grammar: press the key, a solid panel replaces the centre of the
screen, arrows adjust, `OK` or 4 s idle dismisses. No animation, no translucency (see §8).

### MODE

Three tiles in a row — Feed, Thread ‌R, Thread L — current one lit. Arrows move, OK commits.

Improvement over today: `IncFeedMode()` currently ends with `setFeedSelect(-1)`
(`globalstate.cpp:70`), which throws away your pitch every time you change mode. Replace
with **four remembered indices**, one per (mode × unit) pair, so switching feed → thread →
feed returns you to the pitch you were using.

### RATE

The pitch list as a horizontal ticker, current value large in the centre, neighbours dimmed
either side. Arrows step, OK commits.

Display caution: `getCurrentFeedPitch()` returns mm/rev always and negates for
`FM_THREAD_REVERSE` (`globalstate.cpp:137-156`). Rendering "16 TPI" or "4 thou" must index
`threadPitchImperial[]` / `feedPitchImperial[]` directly via `getFeedSelect()`.

### JOG SPEED

Opened by tapping `OK` at rest. Six steps from `jogSpeeds[]`, shown as a percentage bar with
the value large in the centre. Arrows step, `OK` closes.

The scale is `{0.01, 0.05, 0.1, 0.25, 0.5, 1}` → 1 %, 5 %, 10 %, 25 %, 50 %, 100 % of
`jogSpeedPps()`. Two fixes go with the move:

- `incJogSpeed()` clamps against a **hardcoded 5** rather than `ARRAY_SIZE(jogSpeeds) - 1`
  (`globalstate.cpp:83-85`), so adding a speed silently makes it unreachable.
- The `FM_JOG` dispatch inside `next/prevFeedPitch()` goes away with the mode. Those functions
  also return a stale `m_feedSelect` on the jog branch today — a latent bug that disappears
  with the same change.

### STOPS

Shows the travel bar full-width with both stop markers and the live carriage position.

| Gesture | Effect |
|---|---|
| ◀ click, left stop unset | Set left stop **here** |
| ◀ click, left stop set | Flash "hold to clear" — no action |
| ◀ hold, left stop set | Clear the left stop |
| `STOPS` hold | Clear **both**, after a 1 s confirm bar (`LongHold` - the 500 ms `Hold` on the way there is inert) |

The asymmetry is deliberate: setting a stop is cheap to undo, clearing one loses a position
you may have spent time finding. ▶ is the mirror.

Clearing re-anchors the helix onto the surviving stop — that logic already exists in
`LeadscrewStopSync::unsetStop` (`leadscrew.cpp:56-96`) and needs no change.

---

## 5. HALT and ENABLE

**HALT** is always live — it is checked before focus, before overlays, before anything. It
sets `MM_DECELLERATE`, closes any open widget, and returns focus to JOG. It is the one key
whose meaning never depends on context.

**ENABLE** toggles `MM_ENABLED` ↔ `MM_DECELLERATE`, exactly as today. The state chip on the
bottom bar is its readout.

---

## 6. MENU

`MENU` opens a horizontal carousel of tiles; arrows move between them, `OK` activates;
`MENU` again (or `HALT`) closes. A carousel rather than a vertical list because we only have
left/right keys, and a 320×240 landscape panel suits a row of cards.

**Tiles never edit in place.** `OK` either performs a one-shot action or closes the menu and
opens the matching overlay — the same overlays the selector keys open. There is no editing
sub-state: the arrows mean "move between tiles" for as long as the menu is up, full stop. One
grammar, and nothing new to learn.

| Tile | `OK` does | Notes |
|---|---|---|
| **Units** | Toggle mm / inch | `GlobalState` restores the per-(mode,unit) pitch slot itself — do **not** also reset the index |
| **Theme** | Toggle dark / light | Persisted. Refused while the carriage is under power |
| **DRO datum** | Opens the datum overlay | Persisted. Refused while under power |
| **Jog speed** | Opens the jog-speed overlay | The same widget `OK` opens at rest; here for discoverability |
| **Sync** | Sets a sync point | Disabled in feed mode **and while the axis is under power** — see §9 item 12 |
| **Software update** | `setOTA()` | Replaces the half-nut hold. Refused under power |
| **Setup / Wi-Fi** | Reboots into AP mode | Refused under power. See below |
| **Diagnostics** | Live position error, spindle vs leadscrew rates, sync anchor state | Replaces the dead serial debug mode, which stays dead |
| **About** | Firmware version, IP, uptime | Read-only |

### Lathe geometry is web-only

Encoder PPR, stepper PPR, `invertDirection`, the gearbox ratio, leadscrew pitch, jog speed,
acceleration and max speed are **commissioning values**: set once over Wi-Fi with the lathe
offline, and changed only there. **The device must never write them.** The menu covers only what
is worth tweaking mid-session.

This is enforced by the shape of the API, not by discipline: `saveLathePreferences(theme, datum)`
takes values, so there is no struct a caller could get wrong. Geometry exists only as bytes read
back from flash inside that function. The predecessor took a `LatheConfig*` and wrote
`sizeof(LatheConfig)`, so a theme toggle rewrote all nine geometry fields out of an in-RAM
reconstruction — and a stale copy, a missed field or an unseeded struct would each have silently
replaced the user's commissioning.

### Auto-return is rejected

Automatically running back to the other stop after a pass **only works with a servo on the
cross-slide to retract the tool**. Without one the return pass is still cutting and mars the
thread just made. This is a machining fact, not a UI preference. Do not re-propose it.

### There is no separate "zero on set"

Setting the datum-preferred stop already makes it the datum, which already reads `0.00`. A
preference for it would be a no-op field — and a `LatheConfig` addition, which costs a
`CHECKVALUE` bump and wipes every device's Wi-Fi. Considered and dropped.

### Setup tile needs a reboot flag

There is currently no runtime path into config mode: `runWifiSettings()` is file-local in
`main.cpp` and called only from `setup()`. Writing a flag to flash is unattractive because
`WebSettings` and `LatheConfig` share one 4 KB sector that is erased as a unit.

Use **RTC memory** instead — `RTC_DATA_ATTR uint32_t bootToSetup;` survives `ESP.restart()`,
costs no flash wear, and clears on power-cycle. `setup()` then checks
`digitalRead(ELS_PAD_H2) || !checks || bootToSetup == MAGIC`.

### Saving settings from the device

Theme and DRO datum are the first settings the *device* has ever needed to write. Today the
only writer is `setValues()` in `WebSettings.cpp:254-282` — file-local, and dependent on the
live `webServer` global for its argument parsing. So it needs a small exported API:

```cpp
void saveLatheSettings(LatheConfig* config);   // read-modify-write the shared sector
```

It must be read-modify-write: `WebSettings` and `LatheConfig` live in **one 4 KB sector that
is erased as a unit** (`WebSettings.cpp:16-18`), so writing lathe settings without first
re-reading the Wi-Fi credentials would wipe them.

**Adding fields to `LatheConfig` requires bumping `CHECKVALUE`.** The stored blob is shorter
than the new struct, so `droDatum` and `theme` would otherwise read back as flash garbage.
Per `CLAUDE.md`, bumping invalidates saved Wi-Fi *and* lathe parameters, so the device boots
into AP setup and everything must be re-entered — schedule it with the firmware that ships
the redesign, not as a separate release.

---

## 7. Removing the lock

Lock exists to stop an accidental keypress doing something dangerous. It is worth asking
what is actually dangerous:

- **Feed and thread motion is inherently safe when the spindle is stopped.** The leadscrew
  only ever moves in sync with the spindle, so a stray `ENABLE` with the chuck stationary
  moves nothing. A stray pitch change is instantly visible and instantly reversible.
- **Jog is the only thing that moves metal unprompted** — and jog is either hold-to-move
  (dead-man, safe by construction) or a powered run to a stop *you already set*, cancellable
  by any of three keys.

So the lock is guarding the safe operations and not the risky one. Removing it costs
nothing and frees a key. `HALT` is the better answer to the same worry: rather than
preventing motion from starting, make stopping it unmissable.

`GlobalButtonLock` can be deleted outright, along with the lock checks at the top of every
handler in `buttonpad.cpp` and `drawLocked()` in the display.

---

## 8. Visual design

### Layout — 320×240 landscape

```
 0 ┌────────────────────────────────────────────┐
   │ ⚙ THREAD·R    mm    ◈sync         1250 RPM │  status bar
30 ├────────────────────────────────────────────┤
   │                                            │
   │      ◀   1.25 mm   ▶            ╱╱╱╱       │  primary readout
   │          ▔▔▔▔▔▔▔▔▔              ╱╱╱╱       │  (focus underline)
120├────────────────────────────────────────────┤
   │  ·  ·  ·  ·  ▮  ·  ·  ·  ·  ·  ·  ·  ·  ·  │  pitch ticker
140├────────────────────────────────────────────┤
   │   ▐━━━━━━━━━━━●─────────────────────▌      │  carriage travel
   │  L 0.0           12.4 mm         48.0 R    │  (a small DRO)
190├────────────────────────────────────────────┤
   │  ● RUNNING        HALT   MENU   ENABLE     │  state + soft keys
240└────────────────────────────────────────────┘
```

The **carriage travel bar** is new and is the biggest information win: stop positions and
where the carriage sits between them are currently invisible, and they are what you actually
need to know mid-cut. It reads as a small DRO — live position and unit in the centre, each
stop's own position at its end, `——` where a stop is unset. It needs one plumbing change (§9).

### Units

Every number carries its unit, sized down and dimmed so the digits still dominate. They are
not all the same unit:

| Readout | Metric | Imperial |
|---|---|---|
| Pitch — thread | `1.25 mm` | `16 TPI` |
| Pitch — feed | `0.25 mm` | `4 thou` |
| Carriage & stops | `12.4 mm`, 2 dp | `0.488 in`, 3 dp |
| Jog speed | `25 %` | `25 %` |
| Spindle | `1250 RPM` | `1250 RPM` |

Feed in thou/rev while position reads in inches is not an inconsistency — it is what machine
tools do, and matching it is correct. The status bar keeps its `mm` / `inch` chip as the one
place that states the unit mode itself.

Imperial text **cannot** come from `getCurrentFeedPitch()` — see the display caution in §4.
Position is converted for display only; internally everything stays in pulses.

### The DRO datum

A position is meaningless without a zero, and "wherever the machine happened to boot" is the
worst available choice. **Zero is referenced to an endstop.**

Resolution order, first match wins:

| # | Condition | Datum |
|---|---|---|
| 1 | Manual zero set (`OK` held) | That position |
| 2 | Both stops set | The one named by `LatheConfig.droDatum` |
| 3 | Exactly one stop set | That one — the preference cannot be honoured |
| 4 | Neither stop set | Power-on origin, flagged `REL` on screen |

**Sign convention: position increases to the right**, matching
`LeadscrewDirection::RIGHT = 1`. So a left datum reads 0 at the left and counts up rightward;
a right datum reads 0 at the right and counts *negative* leftward. Negative travel is normal
DRO behaviour and needs no special casing.

The datum end shows `0.0` and is underlined; the far end shows the span. A manual zero adds a
`▽` tick on the bar at the zero point and tags the readout `MAN`.

Four details the rules above leave implicit, pinned by `test/test_dro/` and repeated here so
they are not lost in test code:

- **A stop parked at pulse 0 is a real datum.** "Is it set" comes from the stop state alone,
  never from `pulses != 0`. This is the trap an implementation falls into most easily.
- **An unset stop's stored position must be ignored entirely** — it may hold stale junk.
- **Coincident stops** (both set to the same position) still resolve to the preferred *side*,
  because the chosen source is what decides which end of the bar renders as the datum.
- **Translating the `INT32_MIN` / `INT32_MAX` unset sentinels into set/unset flags is the
  caller's job.** `lib/dro` takes explicit booleans and never sees a sentinel.

Two consequences worth designing for:

- **The numbers jump when the datum changes.** Setting a second stop can hand the datum to the
  configured side. This is inherent in the rule, not a bug — but it must not be silent, so the
  readout flashes for ~1 s whenever the datum moves.
- **Manual zero outranks everything** until it is cleared, and it is cleared by re-picking
  Left or Right on the *DRO datum* menu tile. That keeps one authority for "what is zero"
  rather than two competing ones.

### Theme

Dark and light are both good on this panel in different light, so the choice is the user's:
a **Theme** menu tile, persisted in `LatheConfig`.

Implementation is cheaper than it looks, given one asset change:

- Replace the `#define COLOUR_*` constants with a palette struct and a pointer to the active
  one. Both palettes stay compiled in; they are a few dozen bytes.
- On change, call the existing `setDisplayReset()` path — `Display::update()` already rebuilds
  the whole screen when it sees that flag (`ST7789_320_240displaylvgl.cpp:255-256`). No new
  mechanism needed.
- **Regenerate the icons as `A8` instead of `I1`.** This is the load-bearing part. LVGL applies
  recolour for free *only* on A8, where the image is treated as a mask and the blend colour is
  set directly (`lv_draw_sw_img.c:240-252`); every other format with `recolor_opa > 0` falls
  through to `recolor_only()`, which allocates a temp buffer on every draw out of the 64 KB
  LVGL pool. With A8 the same twelve assets serve both themes via
  `lv_obj_set_style_image_recolor()`, and the edges come out anti-aliased instead of jagged.

  Flash cost: A8 is 8 bytes per pixel-byte of I1, so 4 × 128×64 + 8 × 32×32 goes from
  **5.2 KB to 40 KB**. There is ~519 KB of headroom, so this is affordable and it removes the
  need for duplicate light/dark artwork entirely.

The bottom-right soft-key hints mirror the bottom physical row, so the panel is
self-documenting for the two functions that have no on-screen state of their own.

### Type scale

Only Montserrat **14 / 26 / 36 / 48** are compiled in (`lv_conf.h:606-626`), so:

| Role | Size |
|---|---|
| Pitch value | 48 |
| RPM, state word | 36 |
| Chips, travel readout | 26 |
| Labels, hints | 14 |

Adding e.g. `LV_FONT_MONTSERRAT_20` is a one-line `lv_conf.h` change if the 14→26 jump
proves too coarse.

### Colour

**Author every colour pre-swapped.** The panel is R↔B swapped and the existing `COLOUR_*`
constants already compensate (`CLAUDE.md:84-87`).

| Role | Natural RGB | **Write this** |
|---|---|---|
| Run / armed | `#00C853` | `0x53C800` |
| Jog / caution | `#FFAB00` | `0x00ABFF` |
| Halt / fault | `#FF3B30` | `0x303BFF` |
| Idle / inactive | `#6B7280` | `0x80726B` |
| Focus accent | `#38BDF8` | `0xF8BD38` |

Both a dark and a light palette are mocked; the accent/state hues are shared so only the
ground and text tokens differ.

### Renderer constraints

These come from `lv_conf.h` and are hard limits, not preferences:

- **No translucent overlays.** Layer opacity allocates an intermediate buffer bounded by
  `LV_DRAW_LAYER_SIMPLE_BUF_SIZE` = 24 KB; a 300×140 RGB565 panel needs ~84 KB. Overlay
  panels must be **solid fill**.
- **No animation.** `DisplayTask` sleeps 100 ms (`main.cpp:75`), so everything runs at
  10 FPS and any transition looks steppy. Widgets appear instantly. (Dropping the delay to
  33 ms is viable — display is priority 1 on core 1, motion is priority 24 on core 0 — but
  it is a separate change with its own measurement.)
- **Gradients: linear only, 2 stops max** (`LV_USE_DRAW_SW_COMPLEX_GRADIENTS 0`,
  `LV_GRADIENT_MAX_STOPS 2`).
- **Shadows are uncached** (`LV_DRAW_SW_SHADOW_CACHE_SIZE 0`) — recomputed on every redraw.
  Use small blur radii or none.
- **Few distinct corner radii** — only 4 are cached (`LV_DRAW_SW_CIRCLE_CACHE_SIZE 4`).
- **`msgbox`, `dropdown`, `roller`, `switch`, `checkbox` are compiled out.** Every widget
  here is built from `lv_obj` + `label` + `bar` + `line`, all of which are enabled. Confirm
  dialogs are hand-rolled panels, not `msgbox`.

### Icons

Assets are 1-bit indexed with the foreground colour **baked into an 8-byte palette**, and
there is no `lv_image_set_recolor` call anywhere. The 32×32 status icons are already white
(fine for dark); the four 128×64 mode symbols are black and need their palette index-1 bytes
flipped for a dark theme — 8 bytes per file, no regeneration needed.

New glyphs (menu, halt, settings) should be **text**, not icons, to avoid the manual
converter round-trip. There is ~519 KB of flash headroom if that changes.

---

## 9. Firmware work implied

Roughly in dependency order. None of it is on the motion hot path.

1. **Carriage position in mm.** `Leadscrew::getCurrentPosition()` is in pulses, `config` is
   a private member with no accessor, and the only `LatheConfigDerived` is a local in
   `setup()` (`main.cpp:141`). Add `float getPositionMM()` on `Leadscrew` (or hoist the
   config to a global and pass it to `Display`). Same requirement for showing stop positions
   — `getStopPosition()` already exists and has no non-test callers, and returns the
   sentinels `INT32_MIN` / `INT32_MAX` when unset, which is exactly what renders as `——`.
   Imperial divides by 25.4 at the point of render only; internally everything stays in
   pulses.
2. **A UI state machine.** Focus + overlay state, currently nonexistent. Belongs beside
   `ButtonPad`, not in `GlobalState` — it is display-task-local and needs no cross-core
   visibility.
3. **`board.h` remap** to the table in §2.
4. **Rewrite `buttonpad.cpp`** around focus rather than one handler per verb.
5. **Delete** `GlobalButtonLock`, `drawLocked()`, and the dead debug path (`setDebugMode()`
   is an empty function body, and `debugBuffer` is an uninitialised pointer written from the
   4 KB spindle task — a latent crash if anyone re-enables it).
6. **Per-mode pitch memory** (§4) and the `setUnitMode()` index reset (§6).
7. **RTC boot-to-setup flag** (§6).
8. **DRO datum resolution** (§8) — pure arithmetic over `getStopPosition()` and the config
   preference, plus the manual-zero override on `OK`-hold. Worth host tests: the resolution
   order has four branches and a sign convention, and it is cheap to cover.
9. **Theme support** (§8) — palette struct, `LatheConfig` fields, `saveLatheSettings()`, and
   the `CHECKVALUE` bump.
10. **Regenerate the twelve icons as `A8`** (§8). Prerequisite for the theme; also worth doing
    on its own for the anti-aliasing.
11. **Rebuild the display** to the §8 layout, plus overlay rendering.
12. **A real sync action** (§6) — the only genuinely new motion behaviour, and the only item
    that must have host-test coverage before it goes near the lathe.

Items 1–7 and 9–11 are UI-layer and testable by inspection. Items 8 and 12 should follow the
repo's test-first convention (`CLAUDE.md`, "Testing conventions").

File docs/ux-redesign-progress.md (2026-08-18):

# UX redesign — implementation progress

Working log for the `ux-redesign` branch build-out. Written for Martin to read on return.

## State as of the second flash

Everything from the first-hardware feedback is done, and there is now a screen renderer, so
visual claims can be checked instead of argued.

| | |
|---|---|
| Host tests | 354, 12 suites |
| Device build | clean — Flash ~75.9%, RAM 35.1% |
| Screens rendered | 38, in `tools/screenshot/out/` |

**Done since the first flash:** the real palette (dark is now actually dark); the pitch slider
replaced by discrete pips, which is what the mockup always specified and is honest about a
twenty-value list; bands re-spaced; state chip back to 26; soft-key hints removed; the menu
carousel three-across as the mockup; every menu tile given a destination with `OK` closing the
carousel; `DroDatum`, `Diagnostics` and `About` screens built; the Wi-Fi screens brought onto the
palette; the sync **anchor source** surfaced for the first time.

**Known imperfect, deliberately:**
- Light-theme green stop ticks are 2.24:1 on white — below the 3:1 component guideline. Fixing it
  properly means diverging the two palettes' state hues, which §8 says to share.
- Light-theme accent fill vs surface is 1.84:1; the selected tile leans on hue plus dark ink.
- Setup screen: the gap between credential *rows* is airier than label-to-value.
- `diagnostics-error` shows `NOT SYNCED` beside `ANCHOR L stop` — honest (an anchor exists, sync is
  lost) but a reader might expect the anchor to dim.
- `getEstimatedVelocityInPulsesPerSecond()` returns 0 below ~1000 pps, so Diagnostics will read
  `CARRIAGE 0.00` on very slow fine feeds. Firmware behaviour, not display — but it will look like
  a fault on the bench.

**Still not done:** the clear-both confirm bar does not render (the widget opens, but no filling
bar); `GlobalButtonLock` still exists unused; and the imperial-feed 1000× bug is still there by
your decision.

## Read this first

The branch builds clean and every host test passes. Nine of the twelve feature sets are
complete through all three agent stages. **Nothing has been run on hardware** — everything here
is host tests plus a clean device compile, and the parts that touch flash and RTC memory
cannot be tested off-device at all.

Three things want your decision before this goes near the lathe, in order:

1. **Imperial feed is 1000× too slow.** Pre-existing, confirmed, deliberately not fixed — it
   changes how the machine cuts and belongs in its own commit. One line plus a test. Details
   in the section below.
2. **The keypad can drop a key release**, so a dead-man jog can fail to stop itself.
   Pre-existing and not a regression, but the redesign leans on hold-to-jog much harder than
   the old firmware did. Two candidate fixes written up; neither applied.
3. **OTA has no on-device trigger on this branch.** The half-nut hold went with the key and the
   menu that replaces it does not exist yet.

The most valuable thing the reviewers found that I had missed: **a flash erase stalls the
spindle loop on both cores**, so saving a setting mid-cut would lose spindle sync. That one is
fixed — `saveLatheSettings()` now refuses while the carriage is under power.

If you only read one more section, make it "Safety findings from review".

## Baselines (before any change)

| | Value |
|---|---|
| Host tests | 54 cases, all passing |
| Device build | SUCCESS |
| Flash | 1,506,049 / 2,031,616 (74.1%) — ~525 KB headroom |
| RAM | 114,896 / 327,680 (35.1%) |

## Method

Per feature set: **test-author → implementer → reviewer**, each a separate agent, each its own
commit. Models matched to role — Haiku for mechanical work, Sonnet for standard
implementation, Opus for review and for design-heavy logic. Feature sets run in parallel only
where they touch disjoint files.

Verification is done by me between stages (`pio test -e native`, `pio run -e esp32dev_usb`),
not taken from agent self-reports.

### A structural constraint that shaped the decomposition

PlatformIO's test runner builds `lib/` but **not** `src/`. That is why the ESP-only files in
`src/` don't break the native env — and it means anything that needs host tests must live in
`lib/`. So the focus state machine and the DRO datum logic became new pure-C++ libraries
(`lib/ui/`, `lib/dro/`) rather than living in `src/buttonpad.cpp` where they would have been
untestable.

## Feature sets

| ID | Scope | Files | Status |
|----|---|---|---|
| A | GlobalState feed/jog semantics | `lib/global_state`, `lib/config/config.h` | tests + impl done; review outstanding |
| B | Carriage + stop position in mm | `lib/leadscrew` | **complete** — all three stages |
| C | DRO datum resolution | `lib/dro` (new) | **complete** — all three stages |
| D | UI focus state machine | `lib/ui` (new) | **complete** — all three stages |
| D2 | `motionActive` gating + run reconciliation | `lib/ui` | tests done; impl running |
| E | Real sync action | `lib/leadscrew` | not started |
| F | LatheConfig fields + save API + CHECKVALUE | `lib/config`, `src/WebSettings.*` | tests done; impl running |
| G | board.h remap + buttonpad rewrite + lock removal | `src/`, `lib/global_state` | not started |
| H | Icons I1 → A8 | `lib/display/icons` | impl + review done |
| H2 | Restore icon colour parity | `lib/display` | running |
| I | Theme palette + display rebuild | `lib/display` | not started |
| J | RTC boot-to-setup flag | `src/main.cpp` | not started |

### A sequencing mistake worth recording

The design doc's own dependency order (§9) put **theme support before the A8 icon conversion**.
I ran them the other way round, and that opened a real window: LVGL's A8 draw branch is
*unconditional* — unlike every other format it does not gate on `recolor_opa`, it always applies
`draw_dsc->recolor`, whose style default is **black**. The eight 32×32 status icons had *white*
ink baked into their I1 palettes and sit on coloured state rectangles, so they went black-on-green
for the pervasive "engaged" state. Caught in review, fixed by FS-H2 restoring explicit recolour.
The lesson is that the doc's ordering was load-bearing, not decorative.

## Post-flash findings — first time on real hardware

The branch was flashed and looked at. Three things came back.

### 1. It is very grey — and that is a self-inflicted wound

The vivid palette in §8 has **never actually been used**. When the theme system went in, the
acceptance criterion was that dark mode be *byte-identical to the then-current screen*, so
`PALETTE_DARK` kept the old washed-out values (`0x008800` green, `0xCCCCCC` grey) and `init()`
deliberately did not paint a background — leaving LVGL's default light grey `0xF5F5F5`. On glass:
pale grey ground, black text, dim chips.

That constraint was right for a safe refactor and then never lifted. **The step that applies the
actual design was never scheduled.** It is now.

### 2. The soft-key hints go

`HALT / MENU / RUN` along the bottom duplicated what the physical caps will say. Removed; the
space goes to the state readout and possibly the travel band.

### 3. The menu felt disconnected — because most tiles have no destination

Owner's diagnosis: *OK does nothing visible*, and *no feedback that it worked*. Both true.
Diagnostics and About are no-ops, DRO datum has no overlay to open, and the tiles that DO fire
(Units, Theme, Sync) change something off-screen while the menu covers it.

**The rule, decided: `OK` always closes the menu, and you always land somewhere that shows the
result.** The main screen *is* the confirmation — units redraw, the theme changes, the travel bar
re-datums. Tiles whose effect is not visible there open their own screen instead. The single
exception is a refused tile, which stays open with its reason, as it already does.

That means building the missing destinations (Diagnostics, About, a DRO-datum overlay) and
changing `MenuActivate`, which currently leaves the carousel open.

## A screen renderer now exists (`tools/screenshot/`)

Every visual claim on this branch was reasoned from coordinates and font tables and never seen —
which is exactly how the grey shipped. LVGL is portable C, and the only reason it was excluded
from the host build is that `TFT_eSPI` and `Arduino.h` are not. With those shimmed, the real
`Display` renders into a buffer and writes PNGs.

Use it before believing anything about the screen.

## Decisions from the review session

Settled with Martin after the overnight run. These supersede anything below that disagrees.

### The governing principle

**Lathe geometry is web-only and must never be writable from the device.** Encoder PPR, stepper
PPR, gearbox ratio and leadscrew pitch are commissioning values — set once, over Wi-Fi, with the
lathe offline. The on-device menu covers only what you would genuinely tweak *during a session*.

This is not just policy, it fixes three logged defects at a stroke. `ButtonPad` currently
reconstructs all nine geometry fields from the derived config and rewrites every one of them to
flash on a theme toggle. Under the new rule the on-device save re-reads the stored config and
overwrites **only the two preference bytes**. Geometry is then never sourced from RAM, which
removes the `sizeof` padding blind spot, the two-sources-of-truth wart, and the
null-config-writes-defaults path together.

### Settled

| # | Decision |
|---|---|
| 1 | **Geometry web-only.** On-device save touches only preference bytes (above). |
| 2 | **Auto-return is rejected outright** — see below. Not deferred; it cannot work on this machine. |
| 3 | **Zero-on-set**, new preference: setting a stop zeroes the DRO there, but **only for the stop that matches the datum preference**. The preference stays in charge; this just saves a separate zeroing gesture. |
| 4 | **Encoder**: drives pitch at rest, acts as ◀/▶ inside a widget or menu, and is **inert in STOPS focus** — a knob is far easier to nudge than a key, and setting an endstop stays a deliberate keypress. |
| 5 | **Dead-man jog**: poll the matrix while a jog is in flight and stop the moment the key is no longer down. The real fix, not the time-cap approximation. |
| 6 | **Imperial feed 1000× bug: leave it.** Stays a documented known bug, not a to-do. Do not "tidy" it. |
| 7 | **Menu editing**: `OK` on a tile closes the menu and opens the matching overlay. No editing sub-state — one grammar, and it reuses the overlays that already exist. |
| 8 | **Stale leadscrew speed after arrest**: fix by decaying on the gated path. |
| 9 | **Clear-both-stops**: build it as specced, with the 1 s confirm bar. |
| 10 | **New antialiased mode glyphs**, and delete the nine dead assets (~16 KB of flash). |
| 11 | **ENABLE with a widget open**: the first press closes the widget *only*; a second press engages. You cannot commit to a cut while your attention is still in a picker. |
| 12 | **Diagnostics tile** shows live position error, spindle vs leadscrew rates, and sync anchor state. The old serial debug path stays dead. |

### Why auto-return is off the table

Worth recording because it is a machining fact, not a UI preference. Automatically running back
to the other stop after a pass **only works if there is a servo on the cross-slide to retract the
tool first**. Without one the return pass is still cutting, and it mars the thread you just made.
On this machine it would destroy work. Do not re-propose it.

## Decisions taken while you were away

These were judgement calls made to keep moving. All are cheap to reverse — say the word.

1. **`FM_JOG` becomes unreachable, not deleted.** Removing it from the mode cycle leaves no
   public way to reach it (there is no `setFeedMode()`), so the `FM_JOG` branch inside
   `next/prevFeedPitch()` becomes provably dead code and goes. The enumerator itself stays,
   because `lib/display/` and `src/` still reference it and removing it breaks the device
   build. One test that reached FM_JOG by cycling was deleted as unsatisfiable, and replaced
   with one covering the half of the requirement that survives.
2. **`kMenuItemCount = 9`** was added to the `UiState` API — clamping the menu index is
   impossible without a tile count. Nine matches the tiles in spec §6.
3. **HALT fires on `Press` and `Hold`, not just `Click`.** A safety key should act at the
   earliest possible event, and `CancelMotion` is idempotent so a double-fire is harmless.
4. **Icons converted by faithful 1-bit expansion**, so they are A8 but not anti-aliased. True
   smooth edges need regenerating from the SVGs in `assets/` — deliberately not attempted,
   since it would change the artwork rather than just the format.

## A pre-existing bug worth fixing — imperial feed is 1000× too slow

Found by the FS-A review, confirmed independently, **not fixed** — it is outside this
redesign's scope and it changes how the machine actually cuts, so it is your call.

`feedPitchImperial[]` (`lib/config/config.h`) is commented `// defined as thou/rev` but holds
`0.002 … 0.030`. Those are **inches** per rev — 2 to 30 thou, which are the real feed rates for
a lathe this size. The comment is wrong, and two pieces of code disagree about it:

| | Treats the table as | At index 8 (`0.010`) |
|---|---|---|
| `Display::drawPitch()` | inches — renders `* 1000` | shows `10th` ✓ |
| `GlobalState::getCurrentFeedPitch()` | thou — computes `* 25.4 / 1000` | commands **0.000254 mm/rev** ✗ |

They cannot both be right, and the display is. The correct conversion is `* 25.4`, giving
0.254 mm/rev. As it stands, **imperial feed mode feeds at one thousandth of the rate shown on
screen** — the screen says 10 thou and the carriage creeps.

Metric feed and both threading modes are unaffected (they use different tables and paths), and
imperial *threading* is fine — it goes through the TPI branch. It is imperial FEED only, which
is presumably why it has survived.

The fix is one line plus a test asserting the correct value. I have not applied it because it
changes machine motion and belongs in its own commit, not buried in a UI branch.

## Safety findings from review — read this bit first

The FS-D review turned up two genuine hazards in the focus state machine. Both are fixed or
in progress, but they are the most important thing that happened overnight.

**1. Editing endstops while the machine is moving.** `hitLeftEndstop()` is the *sole* arrest
for an engaged feed, and `unsetStop()` sets the stop position to `INT32_MIN` — so clearing a
stop mid-cut does not move the arrest, it deletes it permanently and the carriage feeds into
the chuck. Clearing the *far* stop is quieter but re-extrapolates the helix anchor through an
integer truncation, invisible until the next pass cuts in the wrong place. Setting is no safer:
the display task polls at 10 Hz, so at 1250 rpm × 1.25 mm/rev the captured position is up to
~2.6 mm from where the operator actually pressed — and a stop in the wrong place is worse than
no stop, because it gets trusted on the next pass.

Stop edits are now inert whenever the carriage is under power. The STOPS key still takes focus,
because the travel bar is exactly what you want on screen mid-cut; only the edits are blocked.

**2. The dead-man jog release was conditional.** Three separate early returns in the jog branch
each swallowed the arrow `Release` and left the carriage running with no `JogStop`. A
hold-to-jog is only safe if letting go *always* stops it, so the terminator is now
unconditional and sits directly under HALT. It is deliberately not direction-matched — erring
toward "stop" costs a shortened jog; erring the other way costs a crash.

**3. Pre-existing hazard, NOT introduced here, and not yet fixed.** `src/keyarray.cpp` can drop
a `Release` entirely: `handleRelease()` returns early inside a 10 ms debounce, so a very short
tap emits `Press` with no `Release` at all; and `handleTimer()` emits a release for button `0`
rather than the arrow if any second key is touched during a hold. A dead-man jog that never
receives its release cannot stop itself. Today's `FM_JOG` path has the identical hazard, so
this is not a regression — but a dead-man switch whose release can go missing is only a
dead-man switch by luck. **This is the one I would want your eyes on**, and it is the reason
FS-G ships with a `// HAZARD:` comment rather than a fix.

Two candidate fixes, both behaviour changes I did not want to make unilaterally:

- **Time-cap a continuous jog** — auto-decelerate after N ms with no `Release`. Simple,
  bounded, no new coupling. Costs you a jog that stops itself mid-traverse if you pick N too
  short, and a long deliberate traverse is a legitimate thing to want.
- **Poll the matrix from the display loop** while a jog is in flight, and stop the moment the
  key is no longer physically down. This is a true dead-man rather than an approximation, but
  `getCodeFromArray()` has side effects — it reconfigures pin modes and re-attaches the
  interrupts — so calling it from the display task races the ISR. It would need that scan
  split into a side-effect-free read first.

I lean to the second done properly, because the first only shortens the window rather than
closing it. But it is a real change to how the keypad is read, on the path that moves the
carriage, so it is your call.

## Known regressions on this branch

Tracked, not accidental. All are consequences of removing a key before its replacement exists.

1. **OTA has no on-device trigger.** The half-nut hold that started an update is gone with the
   key, and its designed replacement is the Software update menu tile, which does not exist
   until the display rebuild. **Do not flash this branch to the lathe expecting to update it
   over the air afterwards** — you would be back to USB until the menu lands. If you want a
   temporary binding in the meantime (MENU-hold would be the obvious one) it is a two-line
   change; I did not add it unasked because it is a UI decision and it would need removing
   again.
2. **Units toggle is unreachable.** MODE-hold used to switch metric/imperial; that moves to
   the Units tile, so MODE-hold is currently inert.
3. **Display reset is unreachable.** Thread-sync-hold used to call `setDisplayReset()`; that
   key no longer exists.
4. **The lock is bypassed but not removed.** `GlobalButtonLock`, `getButtonLock()` and
   `drawLocked()` all still exist because `lib/display` calls them — deleting them now would
   break the device build. The new buttonpad simply never consults the lock, and the
   `ButtonPad` constructor unlocks once at startup so the padlock does not sit on screen and
   so the encoder is not silently swallowed (`keyarray.cpp:102`). All of it dies with the
   display rebuild.

## The Sync menu gate — investigated, NOT defeatable

**Resolved: the leak does not occur.** Peak following error after an arrest is always about one
revolution of feed and never more, at every speed and pitch tested, and it always settles to
exactly zero. Left- and right-hand threads mirror exactly. Carriage drift ≤ 3 pulses (0.01 mm)
over twenty revolutions.

But the reasoning on both sides was wrong in interesting ways, so it is worth recording rather
than deleting.

**The review's caveat was false.** It hinged on "if the deceleration planner always lands on
exactly zero speed there is no leak". It does not: 0 at 300 PPS, but **6.9 at 1200 and 142.5 at
3000**, at its own example pitch. The accumulation genuinely happens.

**What actually saves it** is something neither of us spotted: the re-sync *search* runs
**before** the short-circuit return. It re-fires within one spindle revolution, and its re-pin
discards the accumulated error and re-opens the gate — after which `sendPulse()` decays the
speed and everything latches. The error is discarded, never closed, so nothing lurches.

**And the guard is not vacuous** — mutating the re-sync condition to never fire reproduces
exactly the predicted failure: error growing 785.7 → 1573.6 pulses over 10 → 20 revolutions at
0.25 mm, which is precisely one pitch per revolution. Notably 300 PPS still passed under that
mutation, because that is the one speed where the planner really does land on zero. The
review's instinct that this would be "intermittent and much nastier" was right about the shape,
just not the outcome.

The existing arrest tests never exercised any of this: `RH_DecelerationLandsOnLeftEndstop`
unsets its stop, which drops the anchor, so `syncArmed()` is false throughout and the gate is
never live. Three new cases now cover it.

### A real, milder finding that came out of it

If the lathe is **stopped** right after an arrest that left residual speed, nothing drives the
phase onto the gate, so the rescue never runs and `m_leadscrewSpeed` stays frozen at its arrest
value **indefinitely** — measured still present after 20 s of idle. Re-engaging is safe (the
gate still holds, and its firing discards the error), but the next jog starts from a stale
non-zero speed instead of ramping from rest, and `getStoppingDistanceInPulses()` over-estimates
until it decays.

Related fragility: the rescue rests on an **exact-equality** phase match, so if the encoder ever
advances more than one count between `update()` iterations (high RPM plus a stalled loop), the
rescue is deferred a revolution at a time.

Either of two one-line changes closes both — decay the speed on the short-circuit path, or drop
the `m_leadscrewSpeed == 0` condition on the re-pin. **Not applied**: neither is needed for
safety, and both change motion behaviour, so they are yours to call.

## Superseded: the original defeat argument

The final review defeated one of the three safety gates, and the argument is worth reading
because it is not a coding slip.

`motionActive` — the predicate behind every gate — derives "is the carriage under power" from
the **commanded** motion mode. There appears to be a reachable state where that reads
`MM_DISABLED` while `Leadscrew::update()` is still accumulating into `m_expectedPosition`:

1. Setting a stop latches `syncPositionState`, so `syncArmed()` is permanently true.
2. A thread cut arrests on the endstop, setting `MM_DISABLED` **and** `SS_UNSYNC`.
3. `jogMode` is now false, so the accumulate keeps running every iteration.
4. The re-pin that would neutralise it is guarded by `m_leadscrewSpeed == 0`.
5. `m_leadscrewSpeed` only decays inside `sendPulse()` — and the re-sync gate's short-circuit
   `return` skips `sendPulse()` entirely.

If the arrest leaves **any** residual speed the state is self-sustaining: the following error
grows by a pitch per revolution, indefinitely, while the UI honestly reports "not under power".
Sync then renders live, fires, and races the lost-update window the code itself documents as
"only reachable while ENGAGED".

**The caveat that decides it:** if the deceleration planner always lands on exactly zero, the
re-pin fires every iteration and there is no leak. That could not be settled by inspection, so
it is being settled by a host test across several speeds and both thread hands — if it leaks at
some speeds and not others it is intermittent, which is worse.

**The predicate is the real lesson.** "Commanded mode" and "axis is quiescent" are different
questions, and only `Leadscrew` can answer the second. A gate built on the first is guessing.

## The sync action nearly shipped a carriage lurch

Worth reading even if you skip the rest, because it is the clearest case tonight of tests
passing being necessary and not sufficient.

`setSyncPoint()` raised `SS_SYNC` unconditionally — and raising `SS_SYNC` is exactly what
*releases* the re-sync gate. While that gate holds the axis, `update()` keeps accumulating
spindle motion into `m_expectedPosition` with the carriage frozen, so the following error grows
by **a whole pitch per revolution of holding**. Firing the gate normally is what discards that
accumulation; jumping it skipped the discard and handed the axis a large error to close at
maximum speed.

Measured on the host rig: a sync taken a quarter-revolution into a hold moved the carriage
**0.32 mm instantly, into the work**. Worst case approaches a full 1.27 mm pitch. All 13
original tests passed with this present.

Two things follow for the UI work:

- **The Sync menu tile must be gated on the axis being disengaged.** Spec §6 already says
  "against a stopped spindle" — that needs enforcing, not just documenting. There is also a
  residual lost-update race on `m_expectedPosition`, reachable only when syncing while engaged
  and gated, which the same gate closes. And an anchor sampled mid-cut is skewed by the servo
  following error anyway.
- **Do not "simplify" the sync tests.** The two headline "returns every whole pitch" cases
  survive a sign inversion of the anchor, because they never disengage — they only exercise the
  relative feed. The disengage/re-engage cases are the ones doing the work.

## The existing thread-sync tests never exercised the sync anchor

Found while writing the FS-E suite, and worth knowing independently of this branch.

`test/test_thread_sync/`'s `establishSyncAt()` sets a stop at position 0 (which anchors), then
immediately unsets it. With no other stop that sets `syncPositionState = UNSET`, so
`syncArmed()` is false for the entire run. The later re-arm happens with the carriage
elsewhere, and `setStop()` only anchors when the stop position equals the current carriage
position — so no anchor is recorded either.

**Every helix property that suite proves holds purely because the leadscrew is a faithful
relative feed. The anchor plays no part in any of it.** The re-sync block in `update()`
(~lines 300-327) was dead in every test in the repo; the FS-E probe was the first code to
execute it. The good news is that it works — it lands within ~1.3 leadscrew pulses of the
original helix across 300/1200/3000 PPS after a disengage plus a fractional turn.

The reason it was invisible: **the anchor's only observable effect is where the axis resumes
after `SS_UNSYNC`.** Nothing else in the system reads it, so any test that does not disengage
and re-engage cannot tell a correct anchor from a missing one. That is why the new suite leans
on a disengage/re-engage helper — worth knowing before anyone "simplifies" those tests.

Two smaller notes from the same investigation:

- `update()` can drop and re-raise `SS_SYNC` within a single call, so **`SS_SYNC` is not a
  proxy for "engaged"**.
- The `case UNSET:` arm in `update()`'s switch is dead code and its own comment says so
  ("Can we even hit this???"). It is the natural-looking slot for a manual anchor and must not
  be reused as-is — it returns `m_currentPosition`, which would make the anchor mean "wherever
  you are right now", i.e. no phase gate at all.

## A landmine for whoever wires up ZeroDro

`OK`-hold emits `ZeroDro`, and it is deliberately allowed while the machine is engaged — it
moves no metal, and the DRO is a display concern. That reasoning only holds while the zero is
a **display datum**.

If it is ever implemented as `Leadscrew::setCurrentPosition(0)`, it stops being a display
concern: the endstops are stored as absolute positions against the same counter, so rezeroing
mid-cut would silently shift both stops relative to the tool. The datum must live beside the
DRO (a stored `manualZeroPulses`, exactly as `lib/dro` already models it) and must never move
the carriage's own position counter.

`Leadscrew::setCurrentPosition()` exists and has no non-test callers. It is the obvious wrong
answer, which is why it is written down here.

## Questions for Martin

_(accumulated as they arise; nothing here blocks the work below it)_

1. **"Hold STOPS to clear both stops" has no home yet.** The spec (§4) calls for it with a 1 s
   confirm bar, but there is no `ClearBothStops` intent in the `UiIntent` enum, so it is
   currently unimplemented. The test author flagged it rather than inventing one, which was
   the right call. Do you want it? It needs an enum addition plus a confirm-bar interaction
   that nothing else in the design uses — worth confirming it earns that complexity before I
   build it.
2. **Anti-aliased icons.** Worth regenerating the twelve assets from `assets/*.svg` at A8 for
   genuinely smooth edges? It is a visual improvement the current conversion cannot give, but
   it changes the artwork rather than just the encoding, so I have not done it unasked.
3. **The menu has no vocabulary for editing a tile in place.** Spec §6 says the DRO datum tile
   is "◀ ▶ pick Left / Right" and jog speed is "◀ ▶ adjust inline", but while the menu is open
   the arrows map unconditionally to `MenuPrev`/`MenuNext` — there is no notion of an
   "activated" tile. A two-value toggle could be faked by making `OK` cycle it, but the
   six-step jog speed cannot. Either the menu model grows an editing sub-state, or those two
   spec lines change to "OK opens a sub-widget". I lean to the sub-state, but it is a design
   decision, not an implementation one, so it is waiting for you.
4. **The rotary encoder bypasses the focus model entirely.** `KeyArray::updateEncoderPos()`
   calls `next/prevFeedPitch()` directly regardless of `UiFocus`, so turning the encoder while
   the STOPS or JOG SPEED widget is open silently steps the pitch — which contradicts §1's
   "the arrows are the only actuators". Pre-existing, but it used to be masked by the button
   lock, and the new buttonpad unlocks at boot, so it is now live from power-on. It should
   route through `UiState` as `PitchNext`/`PitchPrev` like everything else. Is the encoder
   still fitted and used? That decides whether this is worth wiring or whether the code should
   go.
5. **Should ENABLE also dismiss an open widget?** It does not today. Engaging the leadscrew
   while the RATE widget is up leaves it on screen for up to 4 s with the arrows already
   inhibited. Spec §1 lists the leave conditions as OK / HALT / idle, so this is as designed —
   but it may feel wrong on the bench, and it is a one-line change.
6. **Should a run-to-stop be cancellable by the opposite arrow, or only the same one?** §3 says
   "a second press of the same arrow"; §7 says "cancellable by any of three keys". The
   implementation takes the broader, safer reading — either arrow cancels. Flagging only
   because the two spec lines disagree.

## Infrastructure notes found the hard way

- **Parallel `pio` runs collide.** They share `.pio` and fight over the scons DB lock
  (`.sconsign311.dblite`), which produces spurious `ERRORED` results in suites nobody touched.
  Fix: every agent gets its own `PLATFORMIO_BUILD_DIR` under the scratchpad. If you ever see
  inexplicable `ERRORED` output from a parallel run, this is why — it is not a code fault.
- **Windows `pio test` reports `ERRORED` / `CTRL_BREAK_EVENT` for any non-zero googletest
  exit**, i.e. for any failing test. Cosmetic wrapper behaviour. Judge pass/fail from
  googletest's own printed summary, never from the PlatformIO suite status.

## Log

- Baseline captured; 54/54 host tests green, device build clean.
- Wave 1 test authors launched for A, B, C, D (disjoint files, run in parallel).
- FS-B tests committed (12 cases). Contract set: `getStopPositionMM()` returns `NAN` when
  unset; the pulse sentinels are never converted. Implementer running.
- FS-C tests committed (24 cases). Four implicit rules surfaced and folded back into
  `docs/ux-redesign.md` — stop-at-zero, stale pulse fields, coincident stops, and whose job
  the sentinel translation is. Implementer running.

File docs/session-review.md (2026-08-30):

# Session review — everything decided and found while you were away

Written to be read cold. Ordered by what needs your attention, not chronologically.

---

## 1. Decisions you made, and what they turned into

You settled fourteen questions across three interviews. Each of these is now built.

| # | Decision | Consequence |
|---|---|---|
| 1 | **Lathe geometry is web-only**, never writable from the device | Retired three logged defects at a stroke — see §2 |
| 2 | **Auto-return rejected** — needs a cross-slide servo to retract, else the return pass cuts | Removed from the design permanently, with the *reason* recorded so it is not re-proposed |
| 3 | **Zero-on-set: dropped** | Turned out to already be the behaviour — see §3 |
| 4 | **Encoder**: pitch at rest, ◀/▶ inside widgets, **inert in STOPS** | A knob is easier to nudge than a key; committing an endstop stays a deliberate press |
| 5 | **Encoder dead entirely while under power** (not just at rest) | Simpler rule; costs a live knob inside a widget you opened deliberately |
| 6 | **Dead-man jog: poll the matrix** | **Not yet built** — see §6 |
| 7 | **Imperial feed 1000× bug: leave it** | Documented as a decision, not an oversight |
| 8 | **Menu editing: `OK` opens a sub-widget** | No editing sub-state; one grammar |
| 9 | **`OK` always closes the menu** and you land on the result | Fixed the "menus feel disconnected" complaint |
| 10 | **Clear-both-stops: build it** with the 1 s confirm bar | Built, and it says what it is about to destroy |
| 11 | **STOPS-hold works from the rest screen** | STOPS now takes focus on `Press`, not `Click` |
| 12 | **ENABLE with a widget open: first press dismisses, second engages** | You cannot commit to a cut while your attention is in a picker |
| 13 | **Stale leadscrew speed: fix by decaying on the gated path** | Built and measured |
| 14 | **New antialiased glyphs**, and the arrow points the direction of travel | Right-hand and feed point left; left-hand points right |

---

## 2. Your geometry principle did more work than expected

It was not just scope. `ButtonPad` had been reconstructing **all nine geometry fields** in RAM from the derived config, and `saveLatheSettings()` wrote `sizeof(LatheConfig)` — so **a theme toggle rewrote your commissioned geometry** from that copy every time.

Three separate logged defects all stemmed from it, and your rule removed the cause rather than patching each:

- The `sizeof` assert had a **proven two-byte blind spot** — two more `uint8_t` fields fit in the trailing padding with `sizeof` unchanged, so the assert stays silent while the seeding list misses them.
- `LatheConfigDerived::theme()`/`droDatum()` reported stale values for the rest of the session after a save.
- A null leadscrew in the constructor left the copy holding **compiled-in defaults**, so the first save would have written factory geometry over yours.

The fix is enforced by the shape of the API, not by discipline:

```cpp
bool saveLathePreferences(uint8_t theme, DroDatumPreference droDatum);
```

No parameter can carry geometry, so there is no struct for a caller to get wrong. Geometry now exists only as bytes read back from flash *inside* that function.

---

## 3. Things that turned out to already exist

- **Zero-on-set.** The datum resolves to the preferred stop whenever it is set, so that stop already reads `0.00`, continuously. A preference for it would have been a no-op field — plus a `CHECKVALUE` bump that wipes every device's Wi-Fi.
- **Left-hand thread glyph direction.** When the arrows were flipped, `threadSymbolReverse.c` regenerated **byte-identical**. It was already pointing the right way, which is exactly the exception you identified.

---

## 4. Four pieces of dead code, all of which looked like working features

| Found | Was |
|---|---|
| Debug mode | `setDebugMode()`'s body entirely commented out; its buffer an uninitialised pointer written from the 4 KB spindle task |
| Negative-RPM colour | Tested `abs(rpm) < 0` — always false. `CLAUDE.md` described a symptom that could never have been observed |
| Discrete-button `#else` | Referenced eight deleted macros; `ELS_ENABLE_BUTTON` would still have resolved — to a *matrix code*, not a GPIO |
| Button lock's red LEDs | `ButtonPad` cleared the lock before `Display` ran, so the red branches were unreachable |

---

## 5. What the reviews caught that tests did not

The test-author → implementer → reviewer pipeline earned its cost. The most valuable findings were all in code where **every test passed**.

**A carriage lurch into the work.** `setSyncPoint()` raised `SS_SYNC` unconditionally — which is exactly what *releases* the re-sync gate — skipping the error discard. Measured on the host rig: **0.32 mm of instant carriage movement**, worst case a full pitch. All thirteen sync tests passed with this present.

**An LVGL re-init on every rebuild.** `lv_init()` and `lv_tft_espi_create()` sat outside the `initialised` guard. Harmless until something called `setTheme()` — which was the very next feature. It would have re-initialised LVGL under a live object tree and leaked a display per call.

**A flash erase stalls the spindle loop on both cores.** Nothing in the motion path is `IRAM_ATTR`, so a settings save mid-cut freezes step generation for tens of milliseconds and loses spindle sync. `saveLathePreferences()` now refuses while the carriage is under power.

**Mutation testing found three decorative guards** — tests that passed when the thing they guarded was deleted:
- A bounds test that asserted on whatever index the *previous* test left behind
- A `static_assert` comparing 12 with 90, guarding a label that had 3 px of clearance
- A clear-both safety test that still passed with **half the gate removed**, because the other half covered for it

That last pattern is why every safety-relevant change now gets deliberately broken to see what screams.

---

## 5b. The panel locks out while moving

Added last, and it simplified more than it restricted. **While the carriage is under power, only
`HALT`, `ENABLE` and the arrows' *stopping* functions are live.** No menu, no widget, no tile, no
setting, no DRO zero. Your reasoning: the operator's attention belongs on the tool and the
workpiece, not the screen.

It replaced **five separate "moving, X disabled" states** with one rule, and it means the screen
during motion always shows the travel bar and machine state rather than whatever picker was open.

**The one refinement:** the arrows keep the two functions that *stop* things — the dead-man
release and the run cancel. Disabling them wholesale would have meant letting go of a jog no
longer stopping the carriage, which would have inverted the principle the rule states.

Two things worth knowing:

- **The gate's position in the ladder is load-bearing.** It sits *below* the run-phase
  reconciliation; above it, every inert keypress made while running stops reconciling and the
  "eaten click" the latch exists to prevent comes back. Pinned by a test.
- **Open widgets now close when motion starts.** Unreachable through the panel, but genuinely
  reachable from the web UI or a spindle-driven feed — so this closes a real gap, not just a
  theoretical one. Done in `tick()`, because motion often starts with no keypress at all.

### One decision left for you

Four display hints are now unreachable: the carousel's "stop the carriage first", the STOPS
widget's edit-locked message, the DRO-datum equivalent, and the confirm bar under power.

The **gates** stay regardless — defence in depth on a safety path, and `saveLathePreferences()`
refuses independently of anything the UI does. But the *rendering* for states that can no longer
occur is dead code, and this codebase has already produced four pieces of that (§4). Left in
place for now, recorded here rather than silently kept.

## 6. Still open — needs you

**The dropped-`Release` keypad hazard.** You chose "poll the matrix"; it is **not built**. `keyarray.cpp` can drop a key release entirely — a sub-10 ms tap emits `Press` with no `Release`, and `handleTimer()` emits a release against button `0` if a second key is touched mid-hold. A dead-man jog that never receives its release cannot stop itself. Pre-existing, not a regression, but the redesign leans on hold-to-jog far harder than the old firmware did.

It needs `getCodeFromArray()` split into a side-effect-free read first — it currently reconfigures pin modes and re-attaches interrupts, so calling it from the display task races the ISR. **Worth doing with you present**, since it changes how the keypad is read on the path that moves the carriage.

**The imperial feed bug**, by your decision. `feedPitchImperial[]` is commented thou/rev but holds inches; the display reads it correctly and `getCurrentFeedPitch()` does not, so imperial *feed* commands 1/1000 of what the screen says. Metric and both threading modes are unaffected.

**Bench checks, in order:**
1. **Key mapping before caps are made.** The layout assumes the top row reads 9, 17, 33 left to right — an assumption about the loom that no source file can prove.
2. **A settings save preserves Wi-Fi.** Commission deliberately odd geometry, toggle Theme, reboot, confirm geometry and network both survived.
3. **Does the palette read under shop lighting**, and is the pip scale legible at arm's length.
4. **Does a one-second hold to clear both stops feel right**, or long.

**Known imperfect, deliberately:**
- Light-theme green stop ticks are 2.24:1 on white — below the 3:1 component guideline. Fixing it properly means diverging the two palettes' state hues, which §8 says to share.
- `getEstimatedVelocityInPulsesPerSecond()` returns 0 below ~1000 pps, so Diagnostics reads `CARRIAGE 0.00` on very slow fine feeds. Firmware behaviour, not display — but it will look like a fault.

---

## 7. The screen renderer is the thing worth keeping

`bash tools/screenshot/render.sh` renders the **real** `Display` class on the host against the project's own `lv_conf.h` and writes 41 PNGs. Only `Arduino.h`, `SPI.h`, `TFT_eSPI.h` and `lv_tft_espi_create()` are shimmed; everything else is production code.

It exists because **the grey shipped past thirty `static_assert`s.** They proved nothing overlapped and not one could tell me the screen was the wrong colour. Within minutes of first running it, it found:

- Dark `colourDisabled` at **1.5:1** — the `IDLE` state word was invisible, so the rest screen showed no readable machine state
- Light `textDim` on `colourDisabled` at **1.05:1** — unselected mode tiles were blank slabs
- The pitch ticker reading as a **fill bar**, the exact thing its own comment said it must not
- The OTA progress bar rendering **orange**

Each image proves itself: the framebuffer is pre-filled with a magenta sentinel and the surviving count must be zero, so a blank render cannot pass as success.

**Gallery:** https://claude.ai/code/artifact/be9f8ac9-15ae-4f76-bc3f-6b4c8fbe07f4

### One caution about running it

It is a multi-minute cold build with shared mutable state in `link.rsp`. **Run one at a time, from a shell with the full MSYS2 toolchain on PATH.** Four separate failures during one small change came from getting this wrong — a persisted working directory, `find` resolving to Windows' `find.exe`, three concurrent renders corrupting the response file, and `bash -lc` discarding a prepended PATH. None were code faults.

---

## 8. Numbers

| | Start of session | Now |
|---|---|---|
| Host tests | 54 | **376** |
| Suites | 7 | 12 |
| Flash | 74.1% | 75.9% |
| Rendered screens | 0 | **41** |
| Commits on branch | 0 | **72** |

New host-tested libraries: `lib/ui` (focus model, 226 cases) and `lib/dro` (datum resolution, 26 cases) — both pure C++, both created specifically so the logic could be tested at all, since the native runner never builds `src/`.

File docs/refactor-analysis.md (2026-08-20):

# HalfNutELS - Component Design Analysis & Refactor Plan

Prioritized, constructive analysis of the firmware's component design, with concrete
directions and risk/effort estimates. This project was assembled from someone else's
partly-broken code, so the intent here is to chart a safe path forward, not to assign
blame.

Scope notes:

- **Bugs are report-only.** The confirmed regression and robustness findings are already
  documented in `docs/websettings-review.md` and are **not** duplicated here. This document
  is about *design*, not defects.
- **Part B (applied refactors)** is summarized at the end. Only changes provable-safe by the
  passing pinning tests (`test_latheconfig`, `test_leadscrew`, `test_smoke` = 18 tests) were
  applied; `test_regression` remains failing **by design**.
- Every claim below was verified in the source; citations are `file:line` against the current
  working tree.

---

## Priority summary

| # | Area | Severity | Effort | Group |
|---|---|---|---|---|
| A1 | Extract repeated positive-modulo idiom | low | trivial | safe/mechanical (**DONE**) |
| A2 | Remove stale/dead code (`TestSpindle.h`, `//m_accumulator`) | low | trivial | safe/mechanical (**DONE**) |
| A3 | Commit the native test harness; fix the stale committed test double | **high** | low | safe/mechanical |
| A4 | Build/config hygiene (name, Teensy vestiges, `ELS_USE_RMT`) | medium | low-med | medium |
| A5 | `LatheConfigDerived` getter boilerplate + precompute derived values | medium | medium | medium |
| A6 | Abstract spindle/encoder interface (remove the .cpp-swap test hack) | medium | medium | medium |
| A7 | Split `GlobalState` god-singleton; make the task hand-off thread-safe | high | large | large/architectural |
| A8 | Decompose the `Leadscrew` god object | high | large | large/architectural |
| A9 | Rework the WebSettings model (form/parse/persist registry) | high | large | large/architectural (do NOT touch now) |

---

## Group 1 - Safe / mechanical

### A1. Repeated positive-modulo idiom (DONE in Part B)

**Problem.** The Euclidean "always-positive modulo" idiom `((x % m) + m) % m` was copy-pasted
at four sites, three of them in deeply-nested one-liners:

- `lib/leadscrew/leadscrew.cpp:60`, `:69`, `:299` (wrapping into `encoderPPR`)
- `lib/spindle/TestSpindle.cpp:38` (wrapping into `ppr`)

**Why it matters.** The idiom is easy to get subtly wrong, and in fact the hardware spindle
diverges from it: `lib/spindle/ESPSpindle.cpp:49` uses `(position + ppr) % ppr`, which is only
correct for `position >= -ppr` and can return a negative result otherwise. So the *tested*
double and the *shipped* code compute wrapping differently - a testing-fidelity gap hiding
behind duplicated math. (The ESP divergence is a latent bug; left report-only.)

**Direction (applied).** Added a single well-named helper
`inline int positiveModulo(int value, int modulus)` to `lib/config/config.h:23` and used it at
the four sites with **identical integer semantics**. The `ESPSpindle.cpp` site was deliberately
left alone (different semantics, not covered by the native tests) - unifying it is a behavioral
change that belongs behind the fix, not this refactor.

**Risk/effort:** trivial / verified by 18/18 passing tests.

### A2. Dead and stale code (DONE in Part B)

- `lib/spindle/TestSpindle.h` - **removed.** It declared an obsolete `TestSpindle` class with a
  no-arg constructor and referenced the deleted macro `ELS_SPINDLE_ENCODER_PPR`. Nothing
  included it (verified by grep); it would not compile if it were.
- `//m_accumulator` - **removed** the two inert commented-out fragments
  (`lib/leadscrew/leadscrew.h:67`, `lib/leadscrew/leadscrew.cpp:27`). The accumulator concept
  was abandoned; the leftover comments mislead.

**Remaining, NOT applied** (kept as proposals to keep the diff minimal and mechanical):

- `lib/leadscrew/leadscrew.cpp:272` - a commented-out `// m_currentDirection = ...` inside an
  empty `else` branch. Removing it would leave a bare empty `else`; it arguably documents the
  deliberate decision *not* to reset direction there. Left as-is.
- The stale doc comments referring to "the accumulator" (`leadscrew.h:80-83`,
  `leadscrew.cpp:336-337`) - rewording is a judgement call, not obviously inert.
- The entirely commented-out body of `GlobalState::setDebugMode` (`globalstate.cpp:18-48`) -
  see A7; this is why the debug path is dead (below).

### A3. The native test harness is uncommitted, and the committed test double is broken

**Problem.** This is the most urgent hygiene issue and was discovered while running Part B.
The whole host test harness is **untracked / uncommitted**: `test/test_*`, `test/stubs/`,
`scripts/exclude_espspindle_native.py`, and `docs/` all show as `??` in `git status`. Worse,
the *committed* `HEAD:lib/spindle/TestSpindle.cpp` is a **stale, non-compiling** version
(`Spindle::Spindle()` no-arg ctor, references the removed `ELS_SPINDLE_ENCODER_PPR`,
`consumePosition()` returns `-1`). The working, tests-passing test double exists **only as an
uncommitted modification** to that tracked file.

**Why it matters.** A fresh checkout of `HEAD` cannot build the native tests. The green test
suite depends entirely on files that are not in version control - one `git checkout`/`git clean`
away from being lost. (That is exactly what happened during this task; the double was
reconstructed verbatim and re-verified.)

**Direction.** Commit the harness and replace the stale committed `TestSpindle.cpp` with the
working double in the same commit. Consider renaming it (e.g. `SpindleNative.cpp`) so the
filename stops implying a separate `TestSpindle` class. Add a one-line CI job that runs
`pio test -e native` so this cannot silently rot again.

**Risk/effort:** low / mechanical, but high value.

---

## Group 2 - Medium

### A4. Build / config hygiene

- **Misleading project name.** The repo, and the `platformio.ini` envs `teensy41` /
  `teensy41_debug` (`platformio.ini:14-41`), still advertise Teensy, but Teensy support was
  removed in `cbd1b22`. The live targets are ESP32 (`esp32dev_publish`, `esp32dev_usb`) and
  `native`. The Teensy envs pull `lib_deps` (Adafruit GFX/SSD1306, elapsedMillis) no longer
  used by the ESP32 build. **Direction:** delete the Teensy envs, or gate them clearly as
  unsupported; rename the project to something ESP32-accurate.
  **(DONE)** The Teensy envs are gone from `platformio.ini` and the project was renamed to
  **HalfNutELS** - after the half-nuts an electronic leadscrew makes redundant, rather than after
  whichever microcontroller it happens to run on.
- **Vestigial `leadscrew_io_teensy.h`.** `lib/leadscrew/leadscrew_io_teensy.h` is entirely under
  `#ifdef CORE_TEENSY` (never defined) - dead. It is a clean, self-contained file, so deletion
  is trivial, but it is *not* exercised by any test, so I left it (out of the "provable-safe"
  envelope). **Direction:** delete alongside the Teensy envs. **(DONE)** - the file no longer exists.
- **`ELS_USE_RMT` is always on.** `board.h:19` unconditionally defines it, so the non-RMT
  `sendPulse()` branch (`leadscrew.cpp:144-154`) and the `pinMode(ELS_LEADSCREW_STEP, OUTPUT)`
  fallback (`main.cpp:176`) are dead on hardware. Note the native tests actually exercise the
  *RMT* branch (via a stubbed `rmtWrite` in `test/stubs/Arduino.h`), so the non-RMT branch has
  **no coverage** - do not "clean it up" blindly. **Direction:** either commit to RMT and delete
  the fallback, or make `ELS_USE_RMT` a real build option with a test that covers the other path.
- **Shared magic number.** `CHECKVALUE` (`latheconfig.h:6`) is a single 32-bit magic reused as
  the validity flag for two *different* flash structs (`WebSettings` and `LatheConfig`) with no
  version tag - see A9 and review Finding 5.

**Risk/effort:** low-med / mostly deletions; each is independently testable via a native build.

### A5. Config model: `LatheConfig` POD + `LatheConfigDerived` pass-throughs

**Current shape.**

- `LatheConfig` (`latheconfig.h:9-21`) - a POD struct of raw settings with in-class defaults,
  blitted to/from flash.
- `LatheConfigDerived` (`latheconfig.h:24-49`, `latheconfig.cpp`) - wraps a `LatheConfig*` and
  exposes **nine** hand-written pass-through getters (`latheconfig.cpp:10-36`) that add nothing
  but `return config->field;`, plus the genuinely-derived math (`:38-60`).
- Compile-time constants live in `config.h`; pins/board macros in `board.h`.

**Problems.**

1. **Getter boilerplate.** The nine pass-throughs are pure noise; they exist only so the derived
   math can call `stepperPpr()` instead of `config->stepperPpr`. Any new field means editing the
   struct, the class declaration, and the `.cpp` - three places for zero behavior.
2. **Derived values recomputed every call.** `leadscrewStepsPerMm()` and everything built on it
   (`jogSpeedPps`, `leadscrewMaxSpeedPps`, `accellerationPulseSec`, `leadscrewInitialPulseDelay`)
   are recomputed on each access (`latheconfig.cpp:38-56`) though the inputs only change on a
   settings write. In the `Leadscrew` hot path these are read via `config->...()` inside
   `update()` (`leadscrew.cpp:373,379,391`).
3. **Derived math is where the headline regression lives** - `leadscrewStepsPerMm()`
   (`latheconfig.cpp:38-40`) dropped the `/ leadscrewPitchMm` divisor. Report-only; see review
   Finding 1. It is called out here only because it is *structural*: the derived-math layer is
   the right home for a fix, and consolidating it (below) makes such regressions easier to catch.

**Direction.**

- Drop the pass-through layer. Either give `LatheConfig` the derived methods directly, or expose
  the fields and make the derived quantities **free functions** taking a `const LatheConfig&`.
- Compute the derived set **once** (on load / on settings change) into a small immutable
  `MotionParams` value object that `Leadscrew` and `Spindle` receive by value/const-ref, instead
  of holding a mutable `LatheConfigDerived*` and re-deriving in the ISR-driven loop.
- Add zero-guards at the derivation boundary (division by `gearboxRatioDenominator`,
  `spindleEncoderPpr`) - see review Finding 3.

**Risk/effort:** medium. The pinning tests cover default and a couple of non-default configs
(`test_latheconfig.cpp`), so a same-semantics consolidation is verifiable; changing *when*
values are computed touches `main.cpp` wiring and needs care.

### A6. Hardware coupling: no spindle/encoder seam

**Problem.** `Spindle` is a concrete class that embeds an `ESP32Encoder` by value
(`spindle.h:1,15`) and talks to GPIO in its ctor (`ESPSpindle.cpp:7-18`). `Leadscrew` depends on
the **concrete** `Spindle*` (`leadscrew.h:48`; used at `leadscrew.cpp:176,204,208,295`). There is
no interface seam, so to test `Leadscrew` on the host the harness had to (a) stub the encoder
header (`test/stubs/ESP32Encoder.h`) and (b) swap out the entire `.cpp` via a PlatformIO build
middleware that drops `ESPSpindle.cpp` and compiles a hand-written double instead
(`scripts/exclude_espspindle_native.py` + `lib/spindle/TestSpindle.cpp`). That is a lot of
scaffolding to work around a missing abstraction - and it is why the double can silently drift
from the hardware (A1).

**Direction.** Extract a narrow interface for what `Leadscrew` actually consumes from the
spindle: `getCurrentPosition()`, `consumePosition()`, `getEstimatedVelocityInPPS()`. Note the
codebase already has an abstract `RotationalAxis` (`axis.h:52`) - either widen that seam or add a
dedicated `ISpindle`. `Leadscrew` then depends on the interface; the hardware `Spindle`
implements it; a plain in-memory fake implements it for tests. This **removes the need for both
the encoder stub and the `.cpp`-swap script**, and lets the test double be a first-class class
again rather than an alternate definition of `Spindle::`.

**Risk/effort:** medium. Mechanically it is "introduce interface + change one pointer type,"
which the existing `LeadscrewIO` seam (`leadscrew_io.h`) shows is a proven pattern here. The
risk is churn in the build scripts and ctor wiring in `main.cpp:142-150`.

---

## Group 3 - Large / architectural

### A8. The `Leadscrew` god object

The class admits it itself (`leadscrew.cpp:11-15`: "This is kind of a god object..."). A single
class (`leadscrew.h:38`, inheriting `LinearAxis`, `DerivedAxis`, `DrivenAxis`) currently mixes
**five** distinct responsibilities:

1. **Position & stop model** - `m_currentPosition`, `m_expectedPosition`, `getPositionError()`
   (`leadscrew.cpp:428-430`), the left/right stop state/positions and their API
   (`leadscrew.cpp:51-131`), endstop detection (`leadscrew.cpp:197-201,352-355`).
2. **Spindle-sync model** - `m_syncPositionState`, `m_spindleSyncPosition`, sync extrapolation
   (`unsetStopPosition`, `leadscrew.cpp:56-71`) and re-sync search (`update`,
   `leadscrew.cpp:280-307`). This is where the modulo idiom clustered (A1).
3. **Motion profile / acceleration** - `m_leadscrewSpeed`, `m_currentPulseDelay`,
   `getStoppingDistanceInPulses()` (`:164-167`), `getTargetSpeedDistanceInPulses()` (`:175-188`),
   and the accel/decel/clamp state machine (`:360-423`).
4. **Pulse IO / timing** - `sendPulse()` (`:138-156`, incl. the RMT vs GPIO fork), the
   per-pulse timing gate (`:316-322`), velocity estimation (`:436-439`).
5. **Cross-cutting glue** - reads/writes `GlobalState` motion mode and thread-sync state
   throughout `update()`, and pokes the debug ring buffer (`:397-411`).

**Why it matters.** `update()` is ~230 lines of interleaved concerns with deep conditionals; it
is the ISR-adjacent hot path, the hardest thing to reason about, and the thing most likely to
regress. Every new feature widens it.

**Direction (decomposition).** The author's own TODO already points the way. Suggested seams:

- **`LeadscrewPosition` / stop-and-sync model** - owns current/expected position, stops,
  endstops, and the spindle-sync anchor; pure integer/float math, trivially unit-testable. The
  `positiveModulo` helper (A1) naturally lives near here.
- **`MotionProfile`** - owns speed, pulse delay, accel/decel; input = target speed + should-stop
  decision, output = next pulse delay. No knowledge of GlobalState or IO.
- **`PulseOutput`** - wraps `LeadscrewIO` / RMT (the `LeadscrewIO` seam already exists and is
  clean - reuse it).
- A thin **`Leadscrew` coordinator** that wires the three together per tick and is the only thing
  that talks to `GlobalState`.

Do this **incrementally, behind the pinning tests**, extracting one collaborator at a time and
re-running `test_leadscrew` after each. The current tests pin stop semantics, jog motion,
spindle-follow, and endstop-disable - a useful (if partial) safety net. Add characterization
tests for the accel/decel and re-sync paths *before* touching them.

**Risk/effort:** large / high risk. This is the core algorithm; sequence it last, after A6 gives
a clean spindle fake and after coverage is broadened.

### A7. `GlobalState` god-singleton and thread-safety

**Problem.** `GlobalState` (`globalstate.h:61`) is a classic singleton used as a global mutable
bus. It mixes at least four unrelated concerns:

- **UI/mode state** - feed mode, unit mode, button lock, jog speed/index, feed-select
  (`globalstate.h:70-81`).
- **Motion state** - motion mode, thread-sync state, resync pulse count (`:71,73,87`).
- **OTA state** - `OTA`, `OTAbytes`, `OTAlength` (`:64-66`).
- **Debug plumbing** - two **public** raw `volatile DebugData*` pointers `debugBuffer` /
  `debugInit` (`:101-102`) that `Leadscrew::update()` increments directly
  (`leadscrew.cpp:398-411`).

**Thread-safety.** It is read/written from at least two RTOS contexts: the pinned `SpindleTask`
(`main.cpp:80-85` -> `timerCallback` -> `spindle->update()` + `leadscrew->update()`, which both
read and mutate `GlobalState`) and the `DisplayTask` / `loop()` on another core
(`main.cpp:219-220`). Synchronization is **only** ad-hoc `volatile` on a handful of fields
(`:64-66,76-77`); the enum/int state that `update()` mutates (`setMotionMode`,
`setThreadSyncState`) has no `volatile`, no atomics, and no lock. `volatile` is not a memory
model - this is a latent data race, currently "working" by luck of timing and single-word writes.

**Latent hazard.** `getTargetSpeedDistanceInPulses()`/`update()` dereference and increment
`debugBuffer` whenever `getDebugMode()` is true, but `setDebugMode()` is **entirely commented
out** (`globalstate.cpp:18-48`), so `debugBuffer` is never allocated and debug mode can never be
turned on. The debug path is dead - but if anyone re-enables `setDebugMode` without restoring the
allocation, `debugBuffer` is a wild pointer written from the ISR task. Either restore it properly
or delete it.

**Direction.** Split into cohesive owners (`MotionState`, `UiState`, `OtaState`) and define an
explicit, minimal hand-off between the spindle task and the UI/loop - a lock-free
single-producer/single-consumer queue or documented `std::atomic` fields - rather than a shared
mutable singleton. Remove the public debug pointers from the state object entirely (inject a
debug sink if needed).

**Risk/effort:** large / high risk (touches concurrency and the hot path). High value for
correctness. No native coverage of the concurrency, so proceed with hardware validation.

### A9. WebSettings model (do NOT modify now)

`src/WebSettings.cpp` is **off-limits for edits** in this pass (it has uncommitted captive-portal
changes). Design notes only; **bugs are covered in `docs/websettings-review.md` and not repeated
here.**

**Current shape.** The settings page is built by hundreds of `html += "..."` concatenations with
macro helpers (`DEFAULTWEBSETTING`, `DEFAULTLATHESETTING`, `SETCONFIG` at
`WebSettings.cpp:18-25`). Persistence is raw struct blitting straight to flash via `ESP.flashRead`
/ `flashWrite` at fixed offsets (`WebSettings.cpp:14-16,123-131,158-160`), with validity keyed on
a single shared `CHECKVALUE` magic and **no schema/versioning**. Parsing uses throwing
`std::stoi` (`:25`).

**Why it matters (design).** The form layout, the POST-parse, and the persisted struct are three
parallel hand-maintained lists that must stay in lockstep; every new field is edited in three
places and one mismatch corrupts flash (no version tag means a reordered/added field reads stale
bytes back as "valid" - review Finding 5). The manual `html +=` wall is error-prone and mislabels
units (review Finding 6).

**Direction.** Drive everything from **one settings registry**: a table of field descriptors
(name, type, label/unit, min/max/default, offset or accessor). The same table renders the form,
parses/validates the POST (with non-throwing conversion and range clamping), and defines the
persisted layout. Add a struct version tag and a CRC over the payload instead of a bare magic;
erase all flash sectors the writes span. Templated field descriptors keep it type-safe with
little boilerplate.

**Risk/effort:** large. Defer until the captive-portal work lands and there is test coverage for
the settings round-trip (currently none).

---

## Part B - refactors actually applied (all verified, 18/18 green)

Every change below was applied and the suite re-run; `test_latheconfig`, `test_leadscrew`,
`test_smoke` stayed at **18/18 passing** and `test_regression` stayed failing **by design**.
Line endings were preserved (CRLF for the existing `lib/` sources, matching the repo).

1. **Extracted `positiveModulo` helper** - `lib/config/config.h:23-30`. New
   `inline int positiveModulo(int, int)` with identical integer semantics to `((x%m)+m)%m`.
2. **Applied it at every matching site:**
   - `lib/leadscrew/leadscrew.cpp:59`, `:68` (was `:60`,`:69`) - sync-position wrap.
   - `lib/leadscrew/leadscrew.cpp:298` (was `:299`) - expected-sync-position wrap.
   - `lib/spindle/TestSpindle.cpp:38` - native double's position wrap.
   - `ESPSpindle.cpp:49` deliberately **left unchanged** (different `(pos+ppr)%ppr` semantics,
     not covered by native tests - unifying it would be a behavior change / bug fix).
3. **Removed dead `//m_accumulator` comments** - `lib/leadscrew/leadscrew.h:67` and
   `lib/leadscrew/leadscrew.cpp:27`.
4. **Deleted stale `lib/spindle/TestSpindle.h`** - obsolete, unreferenced, non-compiling.

### Top proposals deliberately NOT applied

- **Fix the dropped `/ leadscrewPitchMm` divisor** and the other review bugs - owner chose
  report-only; `test_regression` pins the discrepancy on purpose.
- **Delete the Teensy envs / `leadscrew_io_teensy.h` and collapse `ELS_USE_RMT`** (A4) - safe in
  principle but outside the "provable by passing tests" envelope (the non-RMT branch has no
  coverage; the Teensy env is not built by the native suite).
- **Collapse `LatheConfigDerived` pass-throughs / precompute derived values** (A5) - a real
  improvement but a larger, wiring-touching change better done deliberately.
- **Introduce the spindle interface** (A6) and the **`Leadscrew` / `GlobalState`
  decompositions** (A8, A7) - architectural; require broader coverage first.
- **Any WebSettings change** (A9) - file is off-limits this pass.

### Important operational finding (see A3)

While applying Part B I confirmed the **committed** `HEAD:lib/spindle/TestSpindle.cpp` is the
old broken double and that the working test harness (`test/`, `scripts/`, the good
`TestSpindle.cpp`) is **entirely uncommitted**. The good double was momentarily lost to a stray
`git checkout` during this task and was **reconstructed verbatim** (from its read-back content)
plus the one-line `positiveModulo` change, then re-verified at 18/18. Committing the harness and
replacing the stale double should be the very next step - it is currently the single biggest risk
to the test safety net.

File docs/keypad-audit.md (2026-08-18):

# Keypad audit — why it drops presses

Written against `src/keyarray.cpp` / `src/keyarray.h` at `656e0e9`, in answer to
"there has been some degree of unreliability in the keypad… make sure it's
watertight… is the debouncing logic causing problems?"

Short answer: yes, the debounce is causing it, and there is a smoking gun. But
the debounce is only the trigger — the underlying design couples debouncing to
interrupt *re-arming*, and that is what turns a swallowed edge into a dead
keypad. Tuning the 10 ms constant would not fix it.

## 1. The smoking gun: a swallowed release strands the interrupt arming

The matrix is scanned by `getCodeFromArray()`, which ends with:

```cpp
setupKeys(code == 0);      // true  -> attach RISING  (wait for a press)
                           // false -> attach FALLING (wait for a release)
```

So the pad is only ever armed for *one* edge direction at a time, and the
direction is chosen as a side effect of the last scan. Press and release share
one debounce timestamp and one 10 ms window:

```cpp
void KeyArray::handle()        { if (time < keycodeMillis + 10) return; ... }
void KeyArray::handleRelease() { if (time < keycodeMillis + 10) return; ... }
```

Now take a tap where the key is released less than 10 ms after it was pressed —
a light quick press, or a contact that opens briefly on the way in:

1. **Press.** RISING fires → `handle()` → scan returns a non-zero code →
   `setupKeys(false)` → the pad is now armed for **FALLING**. `keycodeMillis` is
   set to now. The hold timer starts.
2. **Release, <10 ms later.** FALLING fires → `handleRelease()` → the debounce
   test is true → **it returns immediately**. Three things do not happen:
   `setupKeys(true)` is never called, so the pad stays armed for FALLING; no
   `BS_CLICKED` and no `BS_RELEASED` are emitted; and `buttonState` is left at
   `BS_PRESSED`.
3. The key is now physically up, so the line is already low. **No further
   FALLING edge can ever occur.**
4. The next press produces a RISING edge — which nothing is listening for.

**The keypad is dead.** It recovers only when the 1 s hold timer fires, because
`handleTimer()` happens to call `getCodeFromArray()` again, which re-arms via
`setupKeys(code == 0)`. So the observable symptom is *"sometimes a press does
nothing, and then it's fine again"* — with a dead window of up to a second.

This is consistent with the holes already noted in `buttonpad.cpp` ("the
debounce and one-second-rescan holes"), but the consequence is worse than a
dropped event: it is a dropped event **plus** a period where the pad cannot
report anything at all.

### 1a. The same fault can leave a jog running

`UiState` starts a dead-man jog on the arrow **Press** and stops it on the
**Release**. In the sequence above the Release is never emitted, and the 1 s
timer resets `buttonState` to `BS_NONE` silently — `handleTimer()` emits nothing
on that path. So the `JogStop` never arrives.

The window is narrow (the release must land inside 10 ms of the press) and a
deliberate human tap is normally 50–150 ms, so this is unlikely to be what has
been seen day to day. It is still a motion command that can be lost, which is
why the fix below removes the possibility rather than narrowing it.

## 2. ISR-unsafe calls, on every single key event

`getCodeFromArray()` calls `pinMode()` six times and `setupKeys()` calls
`attachInterrupt()` three times. Both run **inside** the GPIO ISR (via
`handle()` / `handleRelease()`) and inside the timer ISR (via `handleTimer()`).

`attachInterrupt()` reaches `gpio_isr_handler_add()`, which takes a spinlock and
may allocate; `pinMode()` takes the GPIO lock. Calling either from interrupt
context is unsupported, and the failure mode is a deadlock or a corrupted
handler table rather than anything that announces itself.

Worse for this machine specifically: `buttonInterrupt()`, `buttonInterruptRelease()`,
`handle()`, `handleRelease()`, `handleTimer()`, `getCodeFromArray()` and
`setupKeys()` are **all in flash**, and none is `IRAM_ATTR` (only the trivial
`timerInterrupt` wrapper is). Whenever the flash cache is disabled — every
settings save, every OTA, every capture upload — a keypress in that window
executes unmapped code. We now know all three of those happen regularly.

## 3. A full ring buffer is indistinguishable from an empty one

```cpp
void KeyArray::emitButton() {
  ringBuffer[writeindex] = ...;
  writeindex = (writeindex + 1) % 10;   // no fullness check
}
ButtonInfo KeyArray::consumeButton() {
  if (readindex == writeindex) return { 0, BS_NONE };   // "empty"
  ...
}
```

Ten queued events wrap `writeindex` onto `readindex`, and the reader then sees
the buffer as *empty* — so a burst does not drop the oldest event, it drops
**all ten**. `ButtonPad::handle()` drains at most 10 per pass and the pass is
100 ms apart, so a chattering contact can reach this.

The ring entries are also plain (non-`volatile`) structs written from an ISR and
read from a task, with no ownership protocol beyond the two indices — a reader
can in principle observe a half-written entry.

## 4. Why tuning the constant does not fix it

The 10 ms figure is not really a debounce. A debounce answers *"has the input
settled?"*; this answers *"has it been long enough since the last edge I acted
on?"* — a lockout, keyed on a timestamp shared between two different transitions,
and used to gate the code that re-arms the hardware.

* **Raise it** and more releases fall inside the window — more dead keypad.
* **Lower it** and contact bounce gets through as real events, producing double
  presses and spurious clicks.

There is no value that is safe at both ends, because the two failures are driven
by the same number in opposite directions. That is the definition of a design
that needs replacing rather than tuning.
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

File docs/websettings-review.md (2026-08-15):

# WebSettings Commits — Code Review

Report-only review. No source files were modified. Scope: commits `b0b6137` ("Made all lathe
properties configurable via web") and `5db03d7` ("Improved websetting experience") against parent
`cbd1b22`, plus the uncommitted working-tree captive-portal change to `src/WebSettings.cpp`.

> **Update — Finding 1 (the steps-per-mm regression) has since been FIXED.** The `/ leadscrewPitchMm`
> divisor was restored in `LatheConfigDerived::leadscrewStepsPerMm()`; `test_latheconfig` now pins the
> corrected (pre-websettings) scaling and the `test_regression` suite that documented the defect has
> been retired. Findings 2 onward remain open. The analysis below is preserved as the original review.

## Executive summary

**Runtime behaviour is NOT fully preserved.** Web-configurability was added correctly for most
settings, but one confirmed regression changes motion behaviour at the default configuration:
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

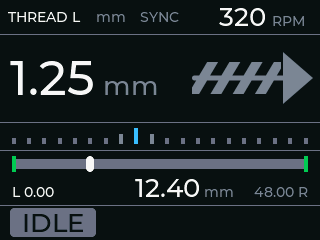
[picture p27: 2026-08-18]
tools/screenshot/out/rest-metric-thread-l.png

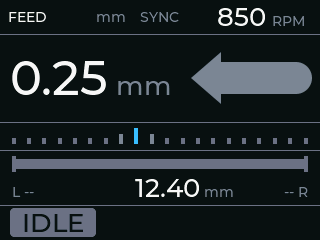
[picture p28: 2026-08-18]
tools/screenshot/out/stops-none.png

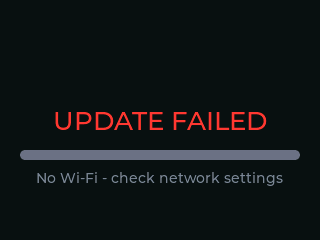
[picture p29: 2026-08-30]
tools/screenshot/out/ota-failed.png

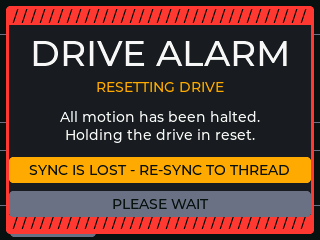
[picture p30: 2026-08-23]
tools/screenshot/out/alarm-clearing.png

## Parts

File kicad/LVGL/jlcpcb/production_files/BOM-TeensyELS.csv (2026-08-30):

Comment | Designator | Footprint | LCSC | Quantity
0.1uF | C3,C4 | C_0805_2012Metric | C49678 | 2
0K | R13,R14 | R_0805_2012Metric | C17477 | 2
10K | R1,R11,R12,R17,R18,R2,R20,R21,R3,R4,R5,R6,R7,R8 | R_0805_2012Metric | C17414 | 14
10uF | C1 | C_0805_2012Metric | C15850 | 1
22uF | C2 | C_0805_2012Metric | C45783 | 1
330R | R10,R19,R9 | R_0805_2012Metric | C17630 | 3
AMS1117-3.3 | U1 | SOT-223-3_TabPin2 | C6186 | 1
BSS138 | Q2,Q3,Q4,Q5,Q6,Q7,Q9 | SOT-23 | C7420339 | 7
Conn_02x03_Odd_Even | J5 | PinHeader_2x03_P1.27mm_Vertical_SMD | C42372553 | 1
ESP32-WROOM-32E | U2 | ESP32-WROOM-32D | C701342 | 1
SW_Omron_B3FS | SW1,SW10,SW2,SW3,SW4,SW5,SW6,SW7,SW8,SW9 | SW_SPST_Omron_B3FS-101xP | C231324 | 10

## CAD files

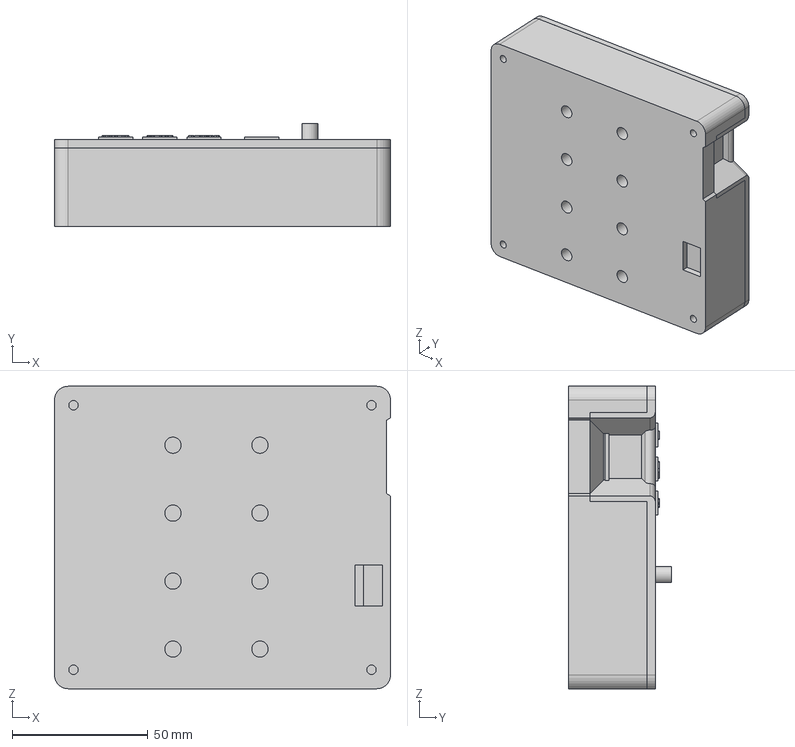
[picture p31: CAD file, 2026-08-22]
cad/Enclosure.step
123.6 x 38.0 x 111.3 mm
Panel
Keycaps
PinHeader_1x14_P2.54mm_Vertical
SOT-23 x 9
R_0805_2012Metric x 21
JST_XH_B4B-XH-A_1x04_P2.50mm_Vertical
SW_SPST_Omron_B3FS-101xP x 10
C_0805_2012Metric x 4
PinHeader_2x03_P1.27mm_Vertical_SMD
SOT-223
TeensyELS_pad
TeensyELS_silkscreen
TeensyELS_silkscreen_1
TeensyELS_soldermask
TeensyELS_soldermask_1
TeensyELS_PCB

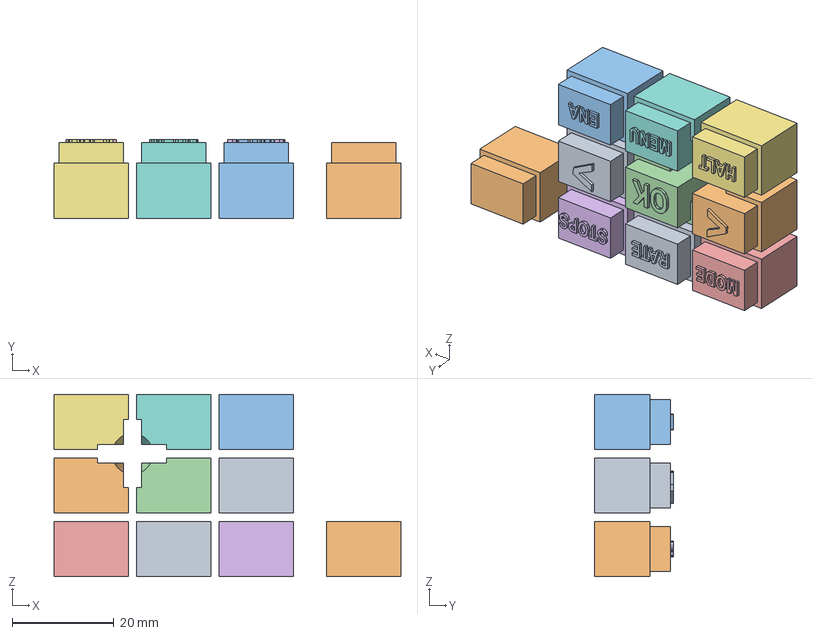
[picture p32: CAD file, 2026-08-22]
cad/Keycaps.step
68.3 x 15.6 x 35.9 mm

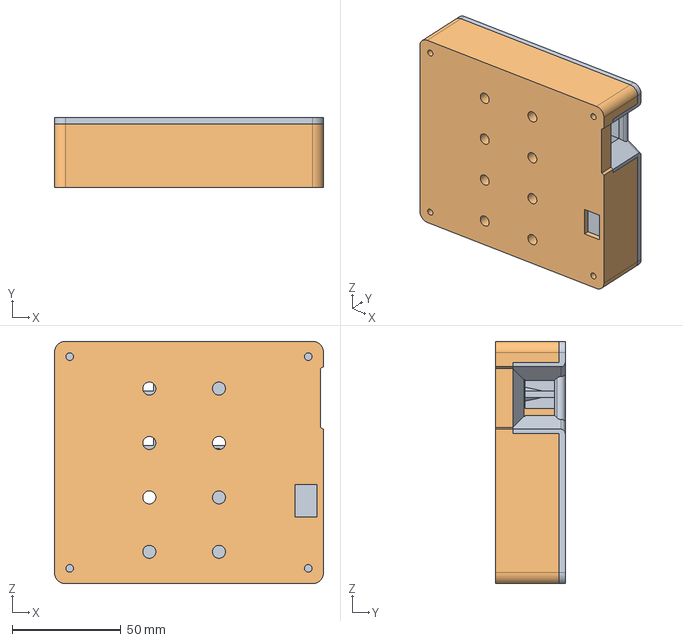
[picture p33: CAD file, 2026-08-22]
cad/EnclosureOnly.step
123.6 x 32.0 x 111.3 mm
Panel

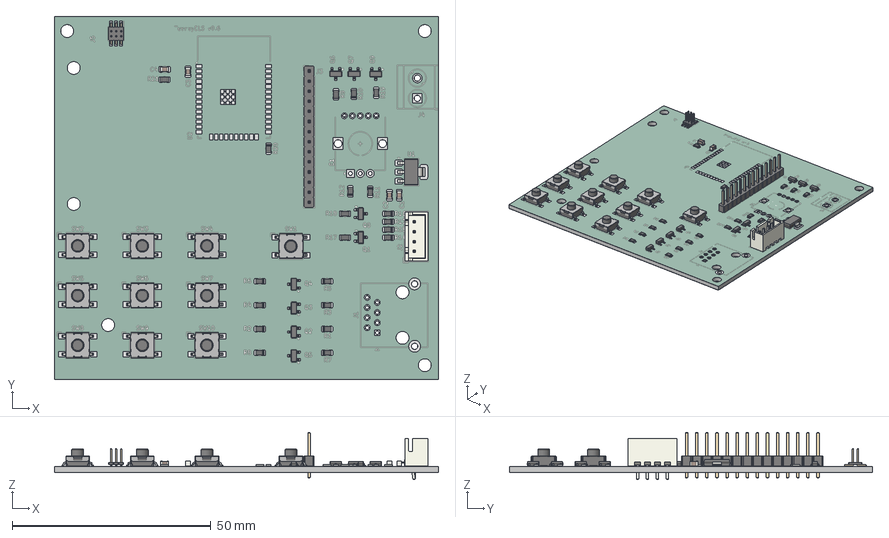
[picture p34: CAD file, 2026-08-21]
cad/board.step
96.6 x 91.3 x 11.9 mm
PinHeader_1x14_P2.54mm_Vertical
SOT-23 x 9
R_0805_2012Metric x 21
JST_XH_B4B-XH-A_1x04_P2.50mm_Vertical
SW_SPST_Omron_B3FS-101xP x 10
C_0805_2012Metric x 4
PinHeader_2x03_P1.27mm_Vertical_SMD
SOT-223
TeensyELS_pad
TeensyELS_silkscreen x 2
TeensyELS_soldermask x 2
TeensyELS_PCB

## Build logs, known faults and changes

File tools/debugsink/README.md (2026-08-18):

# ELS motion-trace capture — sink and analysis

The lathe records a trace of the leadscrew planner from inside its hot loop and
POSTs it here when the carriage stops. This directory is the receiving end plus
the script that reads the result.

## 1. Run the sink on hass.longhome.co.uk

```sh
python3 debugsink.py                                # 0.0.0.0:8088, ./captures
python3 debugsink.py --port 8088 --dir /srv/els-captures
```

Python 3.7+, standard library only — nothing to install. It prints one line per
capture, with the stall figures up front so you know before opening the file
whether it caught the hot loop being starved:

```
20260818-201500  capture-20260818-201500-A1B2C3D4.csv  2000 rows  49.8 s  17 reversals  10 stalls (max gap 8400 us)  fw v0.2.1  (154002 bytes)
```

Leave it running (`tmux`, `screen`, or a systemd unit — a sample one is at the
bottom of this file).

## 2. Configure the device

Boot the ELS into setup mode (MENU → Wi-Fi setup, or hold OK at power-on), join
the **ELS_Wifi** access point, open the setup page, and set:

| Field | Value |
| --- | --- |
| **Debug capture URL** | `http://hass.longhome.co.uk:8088/capture` |

That exact URL is also the field's default, so on a device that has just been
reconfigured from scratch it is already filled in — check it and press Save.

**Prefer `http://` over `https://`.** The device holds the ~105 KB trace in RAM
while it uploads; a TLS session plus the CA bundle costs another ~45 KB on top,
on a board with ~200 KB of free DRAM. Plain HTTP to a machine on your own
network removes that risk entirely. (`https://` does work — the same CA bundle
the OTA updater uses — if the sink is only reachable over the internet.)

Leave the field blank to disable uploading. The capture still records and the
Diagnostics screen still shows it filling; it simply has nowhere to go.

> **This firmware bumps `CHECKVALUE`.** The stored-settings layout changed to
> make room for the URL above, so the first boot after flashing wipes the saved
> Wi-Fi credentials *and every commissioned lathe measurement* and comes up as
> the `ELS_Wifi` access point. Write down the geometry values before flashing.

## 3. Take a capture

1. **Stop the carriage.** The capture tile is refused while anything is moving —
   it allocates ~105 KB, and a trace armed after the cut starts would not
   contain the cut.
2. `MENU` → **Debug capture** → `OK`. The menu closes onto the Diagnostics
   screen, whose title row now reads `REC 0/2000`.
3. Make the cut. The buffer spans about 50 seconds.
   *The Diagnostics screen closes itself the moment the carriage moves* — that
   is the panel's motion lockout ("all of the operator's attention should be on
   the tool, not the screen"), and it applies here like everywhere else. The
   capture carries on regardless; reopen `MENU` → `Diagnostics` once you have
   stopped to see where it got to.
4. When it fills, the capture stops itself. The title reads `FULL: STOP TO SEND`.
5. **Stop the carriage.** As soon as the axis is genuinely at rest (motion
   disabled *and* the deceleration ramp finished) the device connects to Wi-Fi
   on its own and sends: `SENDING TRACE`, then `SENT 2000`.
6. If it says `SEND FAILED` the trace is still in RAM — stop the carriage again
   any time after 30 seconds and it retries. Pressing `OK` on the tile at that
   point throws the trace away instead.

The upload **suspends step generation** for its duration (the Wi-Fi driver and
the motion loop share a CPU core), and the machine is left disengaged
afterwards, so press `ENABLE` again to re-engage. This is why it waits for the
carriage to stop rather than sending as soon as the buffer is full.

## 4. Read the capture

```sh
python3 analyse_capture.py captures/capture-20260818-201500-A1B2C3D4.csv
```

It prints, in this order:

* what the trace is — sample count, span in seconds, effective sample rate, and
  how far the carriage moved overall;
* the **following-error distribution** (median / p95 / p99 / max with its
  timestamp), for both `posError` and the raw `posErrorRaw` before the
  speed-matching term is added;
* the **largest error excursions** — contiguous runs above a threshold, worst
  first, each with its start time, duration, peak error, position, direction and
  planner speed;
* the **starvation correlation** — the section the capture exists for. For each
  large excursion it prints the four samples leading up to the peak, the peak
  itself and the two after, with `loopGapUs` and `spindleDelta` beside
  `posError`, so the causal order is *visible* rather than inferred:

  ```
  EXCURSION 1  peak posError 1200.0 at t=3.0000 s
        t(s)     gap(us)    delta     posError        pos   dir
      2.9750          16        1         -0.9       4641     1
      3.0000        8400       52       1200.0       4680     1  <-- peak
      3.0010          20        1        800.0       5080     1
    verdict: loop gap 8400 us (350x the median) at or just before the peak,
             with a spindle delta of 52 alongside it
             -> consistent with SpindleTask starvation
  ```

  A gap spike followed by a delta spike followed by an error spike is
  starvation of `SpindleTask` and nothing else. An error spike with a flat gap
  and a flat delta means the fault is in the motion maths, and the script says
  so — naming the re-sync gate as the suspect. It ends with an overall verdict
  (all / none / mixed) across the excursions examined;
* every **direction reversal**, with how far the carriage travelled before the
  next one, in pulses *and in degrees of leadscrew rotation* (the units the
  symptom was reported in — pass `--steps-per-rev` if the machine is not the
  default 400 × 2 = 800);
* the **interval between reversals** (n, min, median, mean, max) — the number
  that says whether what was captured is the reported 2–10 s glitch;
* **out-and-back reversals**: a reversal that returned within a second, which is
  the "reverses ~180° then carries on" shape specifically, as opposed to an
  ordinary change of travel direction;
* the largest **position jumps** per sample, with the pulse rate they imply next
  to the planner's own commanded speed — a jump the speed cannot explain is the
  signature of lost or duplicated steps rather than a planned move.

Useful flags: `--top N` (how many rows per table), `--error-threshold PULSES`
(the excursion cutoff; defaults to 10× the median error, floored at 5 pulses).

## 5. Wire format

`text/csv`, one header line then one row per sample:

```
time,posError,posErrorRaw,pulseToTarget,pos,expectedPos,speed,direction,targetSpeed,speedDiff,timeToTarget,loopGapUs,spindleDelta
```

* `time` — **microseconds since the capture was armed**, not raw `micros()`.
* `pos` — carriage position in leadscrew pulses; `expectedPos` is where the
  spindle says it should be.
* `posError` = `posErrorRaw` + `pulseToTarget`, all in pulses.
* `speed` / `targetSpeed` — planner and target, in pulses per second.
* `direction` — commanded direction: `-1` left, `+1` right, `0` unknown.
* `loopGapUs` — microseconds between hot-loop iterations, and `spindleDelta` —
  what `consumePosition()` returned. **Both are peak-held between samples**: each
  row reports the worst its window saw, not an instantaneous reading, so a 2 ms
  stall cannot fall between two rows and vanish. The device also *forces* a
  sample when the gap reaches 2 ms or the delta reaches 8 counts, so an event
  gets its own timestamped row within a millisecond.

The last two columns are appended, so a capture taken before they existed still
parses; the analysis script accepts both widths and says plainly when a trace is
too old to test the starvation hypothesis.

These two replace the old `ELS_STALL_TELEMETRY` serial print, which has been
removed from `src/main.cpp`. It measured the right thing and reported it to a
terminal nobody can watch at the lathe.

Sent chunked (`Transfer-Encoding: chunked`) with these headers, which the sink
uses for the filename and the summary line: `X-ELS-Device` (MAC),
`X-ELS-Version` (firmware), `X-ELS-Samples`.

CSV rather than a binary blob on purpose: the sink writes the body straight to a
file with no decoder, there is no endianness or float-layout contract to get
wrong, and the capture opens in a spreadsheet when the analysis says something
surprising. ~215 KB per capture over Wi-Fi costs nothing.

## 6. PHP drop-in (optional)

If there is already a web server on the box, `capture.php` does the same job —
drop it somewhere served and point the device at it instead. Note that PHP
receives an already-de-chunked body, so it is a much shorter file; the Python
version is the one to prefer, since it needs no web server at all.

## 7. systemd unit (optional)

```ini
[Unit]
Description=ELS motion-trace capture sink
After=network.target

[Service]
ExecStart=/usr/bin/python3 /opt/els/debugsink.py --port 8088 --dir /srv/els-captures
Restart=always
User=els

[Install]
WantedBy=multi-user.target
```

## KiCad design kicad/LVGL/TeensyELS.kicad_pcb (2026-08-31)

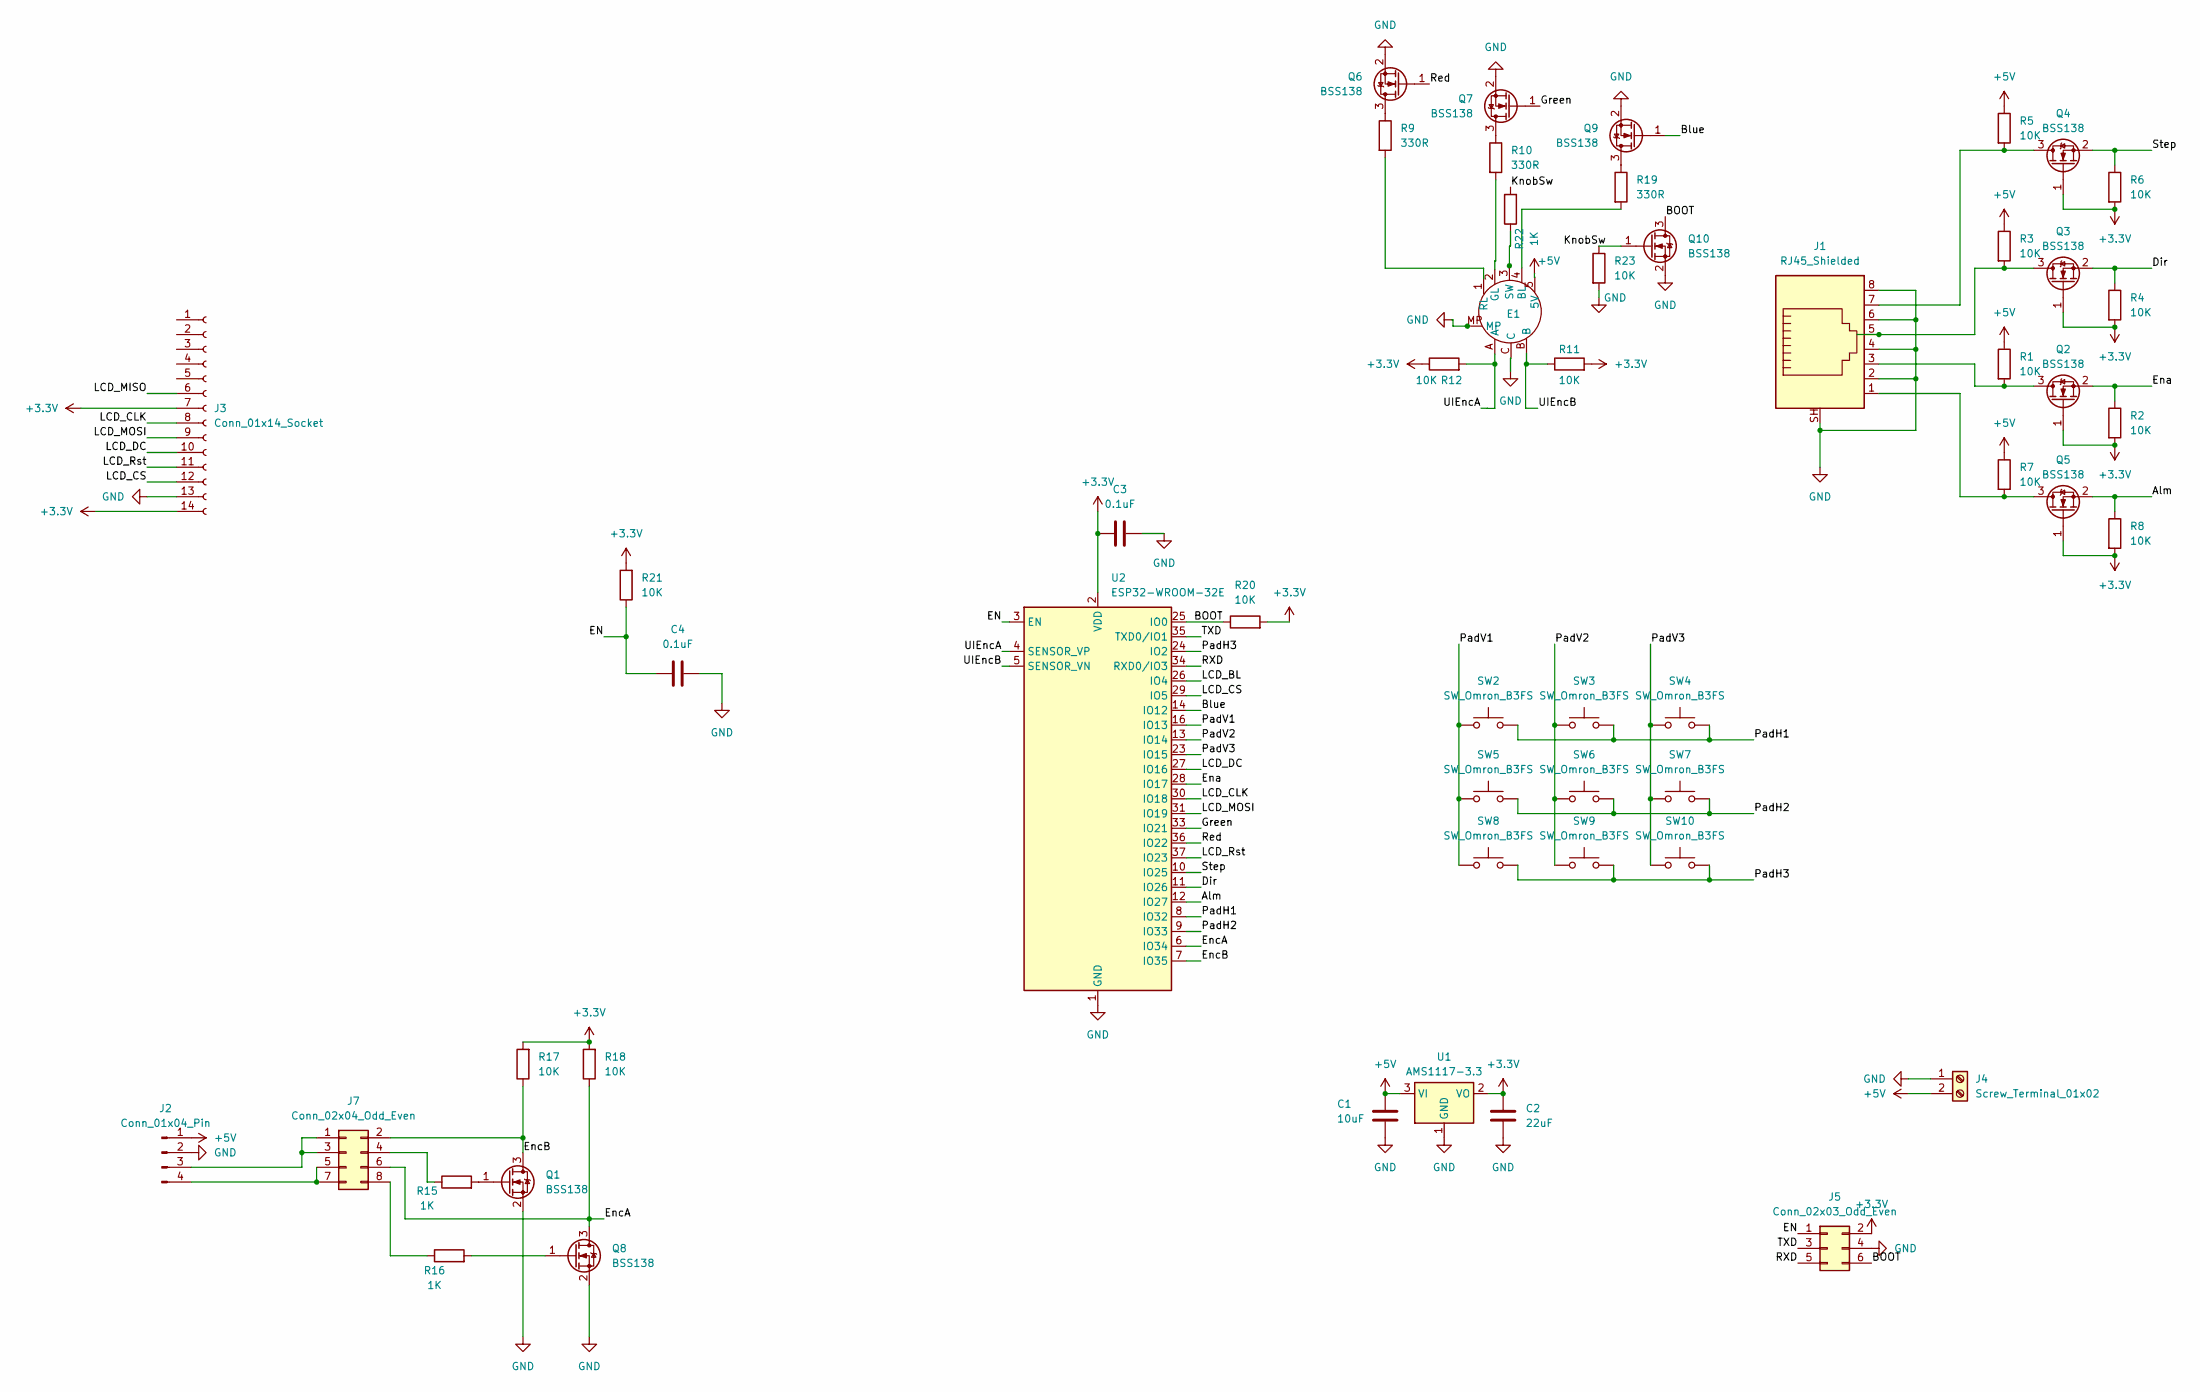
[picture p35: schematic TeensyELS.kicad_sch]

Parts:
C1: 10uF; C_0805_2012Metric
C2: 22uF; C_0805_2012Metric
C3, C4: 0.1uF; C_0805_2012Metric
E1: Sparkfun
J1: RJ45_Shielded; RJ45_RCH_RC01937
J2: Conn_01x04_Pin; JST_XH_B4B-XH-A_1x04_P2.50mm_Vertical
J3: Conn_01x14_Socket; PinHeader_1x14_P2.54mm_Vertical
J4: Screw_Terminal_01x02; TerminalBlock_CUI_TB007-508-02_1x02_P5.08mm_Horizontal
J5: Conn_02x03_Odd_Even; PinHeader_2x03_P1.27mm_Horizontal
J7: Conn_02x04_Odd_Even; PinHeader_2x04_P2.54mm_Vertical
Q1, Q2, Q3, Q4, Q5, Q6, Q7, Q8, Q9, Q10: BSS138; SOT-23
R1, R2, R3, R4, R5, R6, R7, R8, R11, R12, R17, R18, R20, R21, R23: 10K; R_0805_2012Metric
R9, R10, R19: 330R; R_0805_2012Metric
R15, R16, R22: 1K; R_0805_2012Metric
SW2, SW3, SW4, SW5, SW6, SW7, SW8, SW9, SW10: SW_Omron_B3FS; SW_TH_Tactile_Omron_B3F-10xx
U1: AMS1117-3.3; SOT-223-3_TabPin2
U2: ESP32-WROOM-32E; ESP32-WROOM-32D

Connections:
+3.3V: C2.2, C3.1, J3.7, J3.14, J5.2, Q2.1 (G), Q3.1 (G), Q4.1 (G), Q5.1 (G), R2.2, R4.2, R6.2, R8.2, R11.2, R12.1, R17.2, R18.2, R20.2, R21.2, U1.2 (VO), U2.2 (VDD)
+5V: C1.2, E1.5 (5V), J2.1, J4.2, R1.1, R3.1, R5.1, R7.1, U1.3 (VI)
/Alm: Q5.2 (S), R8.1, U2.12 (IO27)
/BOOT: J5.6, Q10.3 (D), R20.1, U2.25 (IO0)
/Blue: Q9.1 (G), U2.14 (IO12)
/Dir: Q3.2 (S), R4.1, U2.11 (IO26)
/EN: C4.1, J5.1, R21.1, U2.3 (EN)
/Ena: Q2.2 (S), R2.1, U2.28 (IO17)
/EncA: J7.6, Q8.3 (D), R18.1, U2.6 (IO34)
/EncB: J7.2, Q1.3 (D), R17.1, U2.7 (IO35)
/Green: Q7.1 (G), U2.33 (IO21)
/KnobSw: Q10.1 (G), R22.2, R23.1
/LCD_BL: U2.26 (IO4)
/LCD_CLK: J3.8, U2.30 (IO18)
/LCD_CS: J3.12, U2.29 (IO5)
/LCD_DC: J3.10, U2.27 (IO16)
/LCD_MISO: J3.6
/LCD_MOSI: J3.9, U2.31 (IO19)
/LCD_Rst: J3.11, U2.37 (IO23)
/PadH1: SW2.2, SW3.2, SW4.2, U2.8 (IO32)
/PadH2: SW5.2, SW6.2, SW7.2, U2.9 (IO33)
/PadH3: SW8.2, SW9.2, SW10.2, U2.24 (IO2)
/PadV1: SW2.1, SW5.1, SW8.1, U2.16 (IO13)
/PadV2: SW3.1, SW6.1, SW9.1, U2.13 (IO14)
/PadV3: SW4.1, SW7.1, SW10.1, U2.23 (IO15)
/RXD: J5.5, U2.34 (RXD0/IO3)
/Red: Q6.1 (G), U2.36 (IO22)
/Step: Q4.2 (S), R6.1, U2.10 (IO25)
/TXD: J5.3, U2.35 (TXD0/IO1)
/UIEncA: E1.A, R12.2, U2.4 (SENSOR_VP)
/UIEncB: E1.B, R11.1, U2.5 (SENSOR_VN)
GND: C1.1, C2.1, C3.2, C4.2, E1.C, E1.MP, J1.2, J1.4, J1.6, J1.8, J1.SH, J2.2, J3.13, J4.1, J5.4, Q1.2 (S), Q6.2 (S), Q7.2 (S), Q8.2 (S), Q9.2 (S), Q10.2 (S), R23.2, U1.1 (GND), U2.1 (GND), U2.15 (GND), U2.38 (GND), U2.39 (GND)
unnamed: E1.4 (BL), R19.2
unnamed: E1.2 (GL), R10.2
unnamed: E1.1 (RL), R9.2
unnamed: E1.3 (SW), R22.1
unnamed: J2.3, J7.1, J7.3
unnamed: J2.4, J7.5, J7.7
unnamed: J7.4, R15.1
unnamed: J7.8, R16.1
unnamed: Q1.1 (G), R15.2
unnamed: J1.3, Q2.3 (D), R1.2
unnamed: J1.5, Q3.3 (D), R3.2
unnamed: J1.7, Q4.3 (D), R5.2
unnamed: J1.1, Q5.3 (D), R7.2
unnamed: Q6.3 (D), R9.1
unnamed: Q7.3 (D), R10.1
unnamed: Q8.1 (G), R16.2
unnamed: Q9.3 (D), R19.1

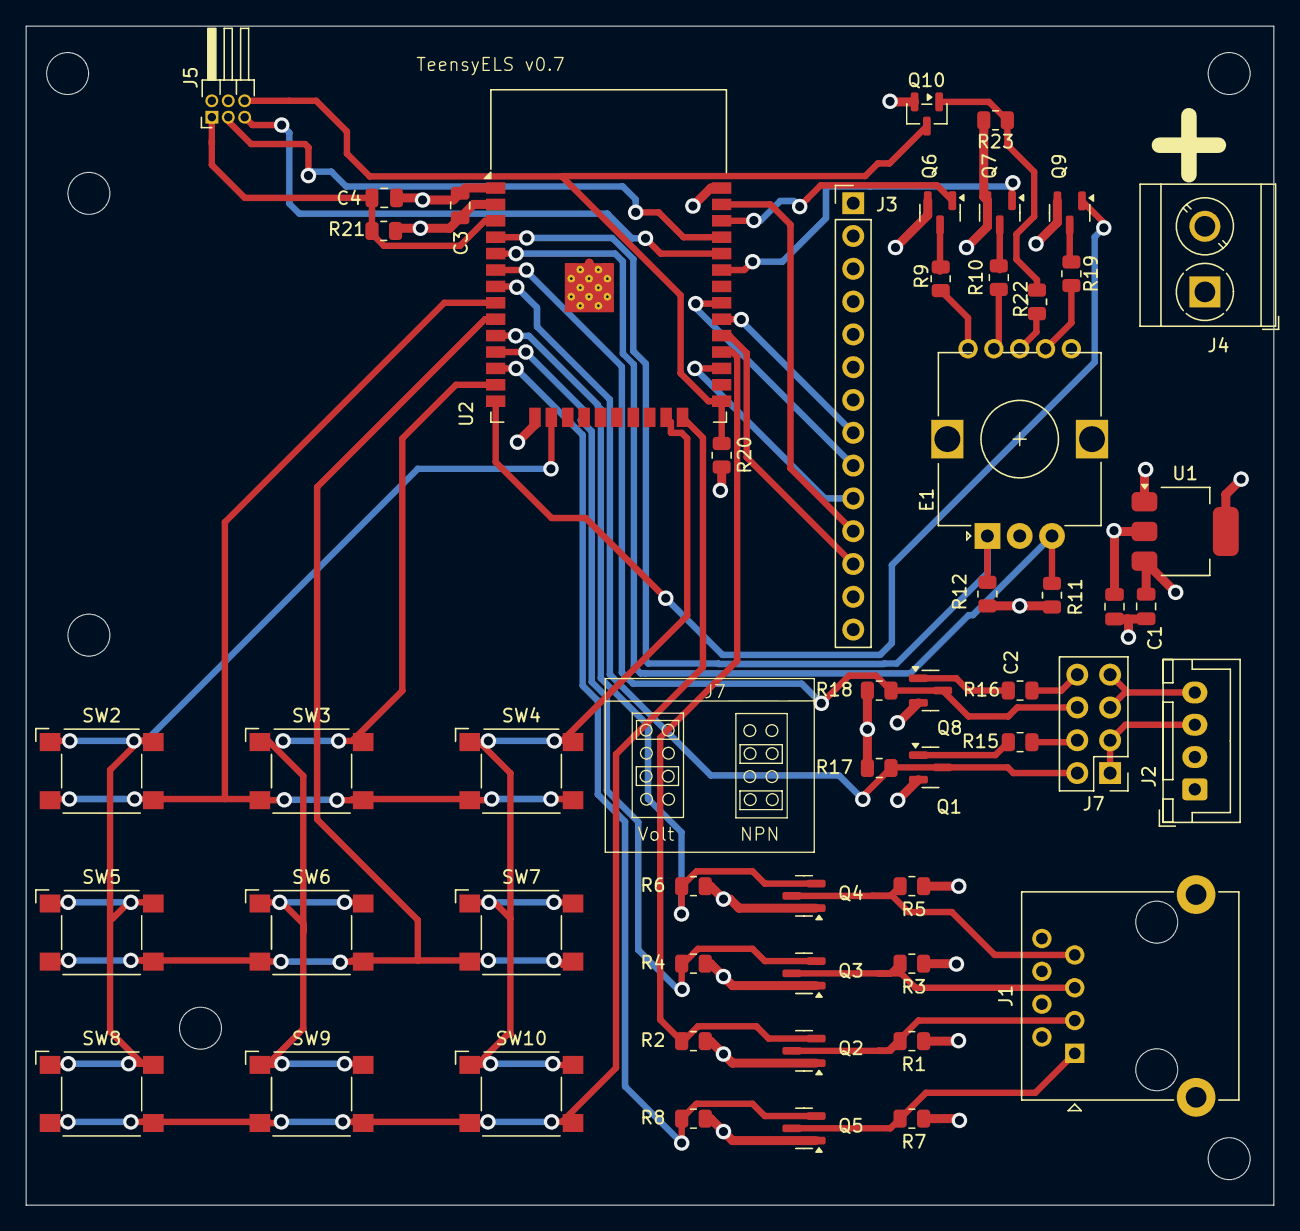
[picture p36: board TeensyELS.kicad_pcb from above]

Board: 4 copper layers, 96.6 x 91.3 mm, 53 parts (0 on the bottom side), 47 nets.

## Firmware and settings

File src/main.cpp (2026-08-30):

// Libraries
#include <Arduino.h>
#include <SPI.h>
//#include <Wire.h>
#include <globalstate.h>
#include <leadscrew.h>
#include <spindle.h>

#include "WebSettings.h"

#include "ESPCommsManager.h"
#include <WiFi.h>

#include "alarm.h"
#include "buttonpad.h"
#include "config.h"
#include "DebugSink.h"
#include "display.h"
#include "keyarray.h"
#include "setupmode.h"

//#define FULLMONITOR
#include <esp_task_wdt.h>
#include <leadscrew_io_esp.h>
#include "latheconfig.h"


Leadscrew* leadscrew;

KeyArray* keyArray;
ButtonPad* keyPad;
Display* display;
Spindle* spindle;

GlobalState* globalState = GlobalState::getInstance();

LeadscrewIOESP leadscrewIOImpl;

ESPCommsManager commsManager;


// The SpindleTask's handle, set once the task exists (setup(), below) and read
// by src/DebugSink.cpp. Null until then, and null for the whole of AP config
// mode, where the task is never created - the uploader checks.
TaskHandle_t spindleTaskHandle = nullptr;

// How long the boot splash stays up. This is dead time before the machine can
// move, so it is a real cost and not free branding: two seconds is long enough
// to read the version off the screen (the reason the splash carries it) and
// short enough not to be in the way of someone power-cycling to clear a fault.
// The dwell lives here rather than inside showSplash() so the display library
// holds no timing of its own - see the note on that method.
static const uint32_t SPLASH_HOLD_MS = 2000;

int64_t lastcycle;
int cyclecount;
int finalcyclecount;
bool configMode = false;
bool apClientConnected = false;

// Runtime path into config/AP mode (see docs/ux-redesign.md section 6).
//
// This can't be a flash-backed flag: WebSettings and LatheConfig share one 4 KB
// sector that is erased as a unit (see WebSettings.cpp), so a boot-flag write there
// would risk the stored Wi-Fi credentials and burn a flash erase/write cycle on
// every normal boot. RTC slow memory is the right lifetime instead, and it costs
// no flash wear. Do NOT change this to a flash write.
//
// IT MUST BE RTC_NOINIT_ATTR, NOT RTC_DATA_ATTR. The framework's own comments in
// esp_attr.h draw the distinction, and it is exactly the one that matters here:
//
//   RTC_DATA_ATTR   "will keep its value during a deep sleep / wake cycle"
//   RTC_NOINIT_ATTR "will keep its value AFTER RESTART or during a deep sleep"
//
// .rtc.data is re-initialised from the image on a software restart, so with
// RTC_DATA_ATTR this flag was zeroed by the startup code before setup() could
// read it: requestSetupOnNextBoot() rebooted the device and it came up normally
// every time. Holding OK at power-on still worked, because that path reads the
// keypad and never looks at this flag - which is what made the bug look like a
// menu problem rather than a storage one.
//
// .rtc_noinit is not initialised on a COLD boot either, so the flag holds
// whatever the RTC memory happened to contain. That is why the value compared
// against is a distinctive magic rather than a plain 0/1 - 0 and 0xFFFFFFFF are
// the two patterns most likely to appear as uninitialised RTC garbage and would
// false-trigger a setup boot. Keep the magic; it is load-bearing under NOINIT.
#define BOOT_TO_SETUP_MAGIC 0xE15B0071u
RTC_NOINIT_ATTR uint32_t bootToSetup;

void requestSetupOnNextBoot() {
  bootToSetup = BOOT_TO_SETUP_MAGIC;
  ESP.restart();
}


// ---------------------------------------------------------------------------
// The ELS_STALL_TELEMETRY block that used to sit here is GONE, superseded by
// the motion-trace capture (lib/global_state/debugcapture.h, src/DebugSink.cpp).
//
// It measured the right thing - hot-loop gap, worst following error - but it
// reported over Serial, once a second, which is unreadable at the lathe. The
// lathe is the only place the bug reproduces (the bench device has no spindle
// and no cutting load), so everything needed has to travel in the uploaded
// capture. Both of its numbers are now per-sample columns of that capture
// (`loopGapUs`, and `spindleDelta`, which it did not have at all), on the same
// time axis as positionError, which is what makes the starvation hypothesis
// decidable rather than merely plausible.
//
// Deliberately not kept alongside it: two half-instruments in one hot loop is
// how you end up measuring the instrument. The capture costs the loop one
// volatile bool load when it is not running; the telemetry cost a micros() call
// and three compares unconditionally.
// ---------------------------------------------------------------------------

// have to handle the leadscrew updates in a timer callback so we can update the
// screen independently without losing pulses
void timerCallback() {
  if (GlobalState::getInstance()->hasOTA()) {
    commsManager.loop();
  } else {
    spindle->update();
    leadscrew->update();
  }
}


void displayLoop() {
  keyPad->handle();

  display->update();

  // The motion-trace capture's upload poll (src/DebugSink.h). It is here, on
  // the DisplayTask, and NOT in timerCallback() above, deliberately: the whole
  // point of this instrument is that the motion loop gains nothing while it is
  // not capturing, and this is a 100 ms poll of a couple of volatile scalars
  // that does nothing at all until a trace is full AND the carriage is at rest.
  debugCapturePoll(leadscrew);
}

void DisplayTask(void* parameter) {
  // Ensure interrupts are initialised on the right core.  
  keyArray->initPad();
  uint64_t m = 1;
  while (true) {
    displayLoop();

    esp_task_wdt_reset();
    //uint64_t c = micros();
    //uint64_t delay = (100000 - (c - m)) / 1000;
    //if (delay > 0) {
      //vTaskDelay((delay > 100 ? 100 : delay) / portTICK_PERIOD_MS);
    vTaskDelay((100) / portTICK_PERIOD_MS);
    //}
    //m = c + 100000;
  }
}

void SpindleTask(void* parameter) {
  while (true) {
    timerCallback();

    esp_task_wdt_reset();
  }
}

void comms_loop(void* parameters) { commsManager.loop(); }


const char* ssid = "ELS_Wifi";
const char* password = "123456789";

//WiFiServer server;

void runWifiSettings() {
  configMode = true;
  WiFi.mode(WIFI_AP);
  delay(100);
  bool result = WiFi.softAP(ssid, password);
  if (result == true) {
    Serial.println("Access Point Ready");
    Serial.println(WiFi.softAPIP()); // Prints 192.168.4.1
  } else {
    Serial.println("Access Point Failed!");
  }
  IPAddress IP = WiFi.softAPIP();
  Serial.print("AP IP address: ");
  Serial.println(IP);
  //server.begin();
  display->showWifi(ssid, password, IP);
  startWebServer();
}

void setup() {


  Serial.begin(921600);

  pinMode(ELS_PAD_H2, INPUT_PULLDOWN);
  pinMode(ELS_PAD_V2, OUTPUT);
  digitalWrite(ELS_PAD_V2, 1);

  WebSettings* webSettings = getWebSettings();
  LatheConfig* config = getLatheSettings();

  bool checks = (webSettings->check == CHECKVALUE) && (config->check == CHECKVALUE);

  // Capture and clear the RTC-memory setup request immediately, before we
  // might branch into runWifiSettings() (which never returns to the normal
  // boot path) — otherwise a menu-triggered reboot into setup would loop
  // back into setup mode forever on every subsequent boot.
  bool wantSetup = (bootToSetup == BOOT_TO_SETUP_MAGIC);
  bootToSetup = 0;

  if (digitalRead(ELS_PAD_H2) == 1 || !checks || wantSetup) {
    display = new Display();
    Serial.println("AP setting mode\n");
    runWifiSettings();
  } else {


    Serial.printf("SSID %s\n", webSettings->ssid);
    Serial.printf("password %s\n", webSettings->password);
    Serial.printf("url %s\n", webSettings->url);
    Serial.printf("debugUrl %s\n", webSettings->debugUrl);
    // Boot heap, against which the debug capture trace and the upload
    // (task stack + WiFi) both have to fit. The sizing note in
    // debugcapture.h assumes a number; this prints the real one.
    Serial.printf("heap at boot free=%u largest=%u\n",
                  (unsigned)ESP.getFreeHeap(), (unsigned)ESP.getMaxAllocHeap());


    LatheConfigDerived* derivedConfig = new LatheConfigDerived(config);

    spindle = new Spindle(ELS_SPINDLE_ENCODER_A, ELS_SPINDLE_ENCODER_B, derivedConfig);


    leadscrew = new Leadscrew(derivedConfig, spindle,
      &leadscrewIOImpl,
      derivedConfig->accellerationPulseSec(),
      derivedConfig->leadscrewInitialPulseDelay(),
      derivedConfig->stepperPpr() * derivedConfig->gearboxRatio(),
      derivedConfig->leadscrewPitchMm(), derivedConfig->spindleEncoderPpr());

    keyArray = new KeyArray(leadscrew);
    keyPad = new ButtonPad(spindle, leadscrew, keyArray);
    // ButtonPad owns the UiState; the display only reads it, to know which
    // selector overlay to show. Both run on the DisplayTask (displayLoop()
    // below calls keyPad->handle() then display->update()), so this is a
    // same-task read and needs no volatile or GlobalState round trip -- but it
    // does mean ButtonPad MUST be constructed first, as it is here: the
    // reference is taken now and held for the life of the display.
    display = new Display(spindle, leadscrew, &keyPad->ui());



    // config - compile time checks for safety
    CHECK_BOUNDS(DEFAULT_METRIC_THREAD_PITCH_IDX, threadPitchMetric,
      "DEFAULT_METRIC_THREAD_PITCH_IDX out of bounds");
    CHECK_BOUNDS(DEFAULT_METRIC_FEED_PITCH_IDX, feedPitchMetric,
      "DEFAULT_METRIC_FEED_PITCH_IDX out of bounds");
    CHECK_BOUNDS(DEFAULT_IMPERIAL_THREAD_PITCH_IDX, threadPitchImperial,
      "DEFAULT_IMPERIAL_THREAD_PITCH_IDX out of bounds");
    CHECK_BOUNDS(DEFAULT_IMPERIAL_FEED_PITCH_IDX, feedPitchImperial,
      "DEFAULT_IMPERIAL_FEED_PITCH_IDX out of bounds");

    // Pinmodes


#ifdef ELS_USE_RMT
    rmt_obj_t* leadscreRMT = rmtInit(ELS_LEADSCREW_STEP, true, RMT_MEM_64);
    leadscrew->setRMT(leadscreRMT);
    rmtSetTick(leadscreRMT, 2500);
#else
    pinMode(ELS_LEADSCREW_STEP, OUTPUT); // step output pin
#endif

    pinMode(ELS_LEADSCREW_DIR, OUTPUT);  // direction output pin

#ifdef ELS_UI_ENCODER

#ifdef ELS_IND_GREEN
    pinMode(ELS_IND_GREEN, OUTPUT);
    pinMode(ELS_IND_RED, OUTPUT);
    pinMode(ELS_IND_BLUE, OUTPUT);
    digitalWrite(ELS_IND_BLUE, 0);
#endif
#endif

    // The stepper driver's ENABLE and ALARM lines, and the task that owns them
    // (src/alarm.cpp). This is where the bare pinMode/digitalWrite of
    // ELS_STEPPER_ENA used to be: that pin now has exactly one writer, because
    // a second one would fight the reset pulse that clears a driver fault.
    //
    // Started here, well above the SpindleTask creation at the end of setup(),
    // like everything else that must actually run (see the note down there).
    alarmInit();

    // The discrete-button #else branch that used to sit here has been deleted.
    // It configured nine GPIOs from ELS_*_BUTTON names that no longer exist,
    // and ELS_USE_BUTTON_ARRAY is defined unconditionally in board.h, so it had
    // not been compiled in a long time. Worse than merely dead: after the Mk2
    // remap the ELS_*_BUTTON names are MATRIX CODES, not GPIO numbers, so
    // ELS_ENABLE_BUTTON would still have resolved here and quietly configured
    // the wrong pin. There is no discrete-button hardware left to support.

    // Display Initalisation

    // The splash goes up first and is simply left on screen for the dwell.
    // Blocking here is safe and is the whole mechanism: setup() still owns the
    // CPU at this point -- the priority-24 SpindleTask that will take core 1 is
    // not created until the end of this function -- so nothing is moving, no
    // task is being starved, and no watchdog is armed yet. init() opens with
    // lv_obj_clean(), and that is what takes the splash back off the screen.
    display->showSplash();
    delay(SPLASH_HOLD_MS);

    // The other half of the OTA failure-visibility work, and the only part of
    // it the operator can actually trust: a banner, drawn by the image that has
    // just booted, saying which version is now running.
    //
    // A successful update ends in ESP.restart(), and a reboot is also what a
    // failure, a crash and a power blip look like from the far side of the
    // lathe. So the OTA task blits its outcome into RTC_NOINIT memory before
    // restarting and this picks it up; "UPDATED - now running v1.4.3" exists in
    // the new firmware and nowhere else, which is exactly what makes it proof.
    // Nothing at all happens on an ordinary boot - beginBootNotice() returns
    // false and this whole block costs one magic-word compare.
    //
    // It borrows the existing OTA screen rather than adding anything to the
    // dashboard: the LVGL heap is at ~85% and a "last update" banner would be
    // new objects on the screen that has none to spare (CLAUDE.md).
    //
    // Blocking here is safe for precisely the reason the splash delay above is
    // safe, and for no other: the priority-24 SpindleTask that owns core 1 is
    // not created until the end of setup(), so nothing is moving and no
    // watchdog is armed. DO NOT MOVE THIS BELOW THAT CALL - it would never run.
    // The hold is OtaOutcome::kSuccessHoldMs (2 s), deliberately brisk.
    //
    // The guard count is a boot-time safety net, not a timeout anyone should
    // rely on: only a SUCCESS is ever stored, and its hold is 2 s, but a stored
    // FAILURE would hold for kFailureHoldMs (30 s) and freeze the boot here.
    // Five seconds of pumping is generous for the former and survivable for the
    // latter; the notice is dropped rather than the lathe being held hostage.
    if (commsManager.beginBootNotice()) {
      for (int guard = 0; guard < 100 && !commsManager.bootNoticeDone(); guard++) {
        display->update();
        delay(50);
      }
      globalState->clearOTA();
    }

    display->init();

    leadscrew->setTargetPitchMM(globalState->getCurrentFeedPitch());

    display->update();


    TaskHandle_t spindleTask;
    TaskHandle_t displayTask;
    //TaskHandle_t commsTask;
    // CORE 1 IS THE SPINDLE'S, AND NOTHING ELSE RUNS THERE.
    //
    // Core 0 is where the ESP-IDF puts WiFi, lwIP and the timer service, so
    // leaving the motion loop there meant sharing with every background stack
    // the SDK starts. The display, buttons, OTA task and capture uploader all
    // tolerate being descheduled; the step generator does not.
    //
    // THE SPINDLE TASK IS CREATED LAST, AND THAT IS LOAD-BEARING.
    //
    // setup() runs on the Arduino loopTask, which is ITSELF pinned to core 1 at
    // priority 1. Creating a priority-24 task on core 1 preempts it there and
    // then - permanently, because that loop never blocks - so every statement
    // after the creation call is simply never executed. Created first, as it
    // was, it silently ate the DisplayTask creation two lines below and the
    // whole watchdog setup: the display never initialised and the device sat
    // there printing nothing, which is exactly how the earlier attempt at this
    // swap failed and got reverted (d7a9a7b / f66472d).
    //
    // Everything that must happen at startup therefore happens ABOVE this line.
    //
    // NOTE for anything that writes flash: a flash operation stops the OTHER
    // core and waits for it to acknowledge, so it now needs CORE 1 to respond -
    // and this loop never blocks. That is why the capture uploader lowers this
    // task's priority rather than suspending it (src/DebugSink.cpp); the same
    // applies to any future settings write.
    xTaskCreatePinnedToCore(DisplayTask, "Display", 8000, NULL, 1, &displayTask, 0);
    //xTaskCreatePinnedToCore(comms_loop, "Comms", 16000, NULL, 10, &commsTask, 1);
    disableLoopWDT();
    esp_task_wdt_delete(xTaskGetHandle("IDLE0"));
    esp_task_wdt_delete(xTaskGetHandle("IDLE1"));
    esp_task_wdt_delete(displayTask);
    //esp_task_wdt_delete(commsTask);

    // LAST. See above.
    xTaskCreatePinnedToCore(SpindleTask, "Spindle", 4096, NULL, 24 | portPRIVILEGE_BIT, &spindleTask, 1);
    // Published for the capture uploader, which lowers this task's priority for
    // the duration of a trace upload (src/DebugSink.cpp).
    spindleTaskHandle = spindleTask;
    esp_task_wdt_delete(spindleTask);

    delay(2000);
  }
}

void loop() {
  if (configMode) {
    wifiLoop();
    // Once a device joins the setup AP, switch the display to the "connected"
    // screen that points the browser at the config page.
    if (!apClientConnected && WiFi.softAPgetStationNum() > 0) {
      apClientConnected = true;
      display->showConnected(WiFi.softAPIP());
    }
  } else {
    vTaskDelay(1000);
  }
}

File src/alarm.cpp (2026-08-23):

#include "alarm.h"

#include <Arduino.h>
#include <alarmmonitor.h>
#include <globalstate.h>

#include "board.h"

// The stepper-alarm task. See alarm.h for the division of labour and
// lib/config/board.h for both pin polarities.
//
// WHERE IT RUNS. Core 0, priority 2 - alongside KeyScan, and for the same
// reasons: core 1 belongs to the spindle loop alone (CLAUDE.md), and a poll
// this fast has no business in the 100 ms DisplayTask. Priority 2 puts it above
// the display so a long LVGL repaint cannot stretch the sampling interval, and
// far below the WiFi driver at 23.
//
// Its own task rather than a few lines inside KeyScanTask, even though the two
// have the same shape and cadence: KeyArray is deliberately a pure input device
// that decides nothing and touches no GlobalState (see the note at the top of
// src/keyarray.cpp), and this stops the machine.
//
// WHY IT POLLS AND DOES NOT USE AN INTERRUPT. The same reasoning that took the
// keypad off edge interrupts (docs/keypad-audit.md): an edge scheme has an
// armed state that can be stranded, and a stranded alarm interrupt is a fault
// that never reaches the screen. A level, sampled every few milliseconds and
// integrated, cannot be missed - every sample re-reads the whole truth.
//
// The 5 ms period against AlarmMonitor::kDebounceMs (25 ms) gives five samples
// per decision, so a single dirty reading can never move the state machine.
// Worst case from the driver asserting to the axis being stopped is therefore
// ~30 ms - two orders of magnitude inside the 100 ms the panel would have taken
// to notice, and the reason the stop is issued from here rather than from
// ButtonPad's next pass.
static const unsigned long kAlarmPeriodMs = 5;

// The decision function. File-scope, single-threaded apart from the volatile
// clear-request flag its own header documents (alarmmonitor.h): only the task
// below calls update(), and only ButtonPad calls requestClear().
static AlarmMonitor alarmMonitor;

void alarmRequestClear() { alarmMonitor.requestClear(); }

// GlobalAlarmState is the wire format for AlarmState - the display and ButtonPad
// read the enum off GlobalState rather than reaching into the monitor, so the
// object stays owned by this task. One switch, here, so the mapping exists once.
static GlobalAlarmState publish(AlarmState s) {
  switch (s) {
    case AlarmState::Alarm: return AS_ALARM;
    case AlarmState::Clearing: return AS_CLEARING;
    case AlarmState::Clear:
    default: return AS_CLEAR;
  }
}

static void AlarmTask(void* parameter) {
  (void)parameter;
  GlobalState* globalState = GlobalState::getInstance();
  for (;;) {
    const bool asserted =
        (digitalRead(ELS_STEPPER_ALARM) == ELS_STEPPER_ALARM_ACTIVE_LEVEL);
    alarmMonitor.update(asserted, millis());

    // The enable line, driven unconditionally from the monitor's output rather
    // than only on a change. It is one register write, and it means no path
    // through this loop can leave the drivers switched off - the failure mode
    // that would look, from the operator's chair, like a dead lathe.
    digitalWrite(ELS_STEPPER_ENA, alarmMonitor.enaAsserted() ? 1 : 0);

    if (alarmMonitor.consumeTrip()) {
      // Once per trip: the helix anchor is worthless the moment the driver
      // stops honouring steps, so the sync state goes with it and the operator
      // is told (by the modal) that it has. Not held, unlike the motion mode
      // below - Leadscrew::update() re-asserts SS_UNSYNC on its own once the
      // axis settles at MM_DISABLED, and nothing can raise SS_SYNC while the
      // modal has the panel locked.
      globalState->setThreadSyncState(GlobalThreadSyncState::SS_UNSYNC);
    }

    if (alarmMonitor.active()) {
      // HELD, not written once on the trip edge. The panel does not find out
      // about the alarm until its next 100 ms pass, and in that window the
      // operator could still press ENABLE - so a single write on the edge
      // leaves a window in which the machine can be commanded to move with the
      // fault already latched. Holding it closes that window, and it also
      // covers the other commanders the panel does not speak for: the web UI,
      // and a spindle-driven feed that would otherwise resume by itself.
      //
      // MM_DISABLED and not MM_DECELLERATE, which is what HALT asks for: the
      // motor has already stopped, at the driver, so there is no ramp left to
      // run - and MM_DISABLED is what Leadscrew::update()'s own endstop arrest
      // publishes for exactly the same situation (leadscrew.cpp).
      //
      // Compared first so the common case - no alarm, or an alarm the axis has
      // already settled out of - costs a read and not a write.
      if (globalState->getMotionMode() != GlobalMotionMode::MM_DISABLED) {
        globalState->setMotionMode(GlobalMotionMode::MM_DISABLED);
      }
    }

    globalState->setAlarmState(publish(alarmMonitor.state()),
                               alarmMonitor.inputAsserted(),
                               alarmMonitor.clearFailed());

    vTaskDelay(kAlarmPeriodMs / portTICK_PERIOD_MS);
  }
}

void alarmInit() {
  // No internal pull: the board carries a 10K to +3.3V on this net (board.h),
  // and the ESP32's own ~45K would only fight it.
  pinMode(ELS_STEPPER_ALARM, INPUT);

  // The enable line starts LOW - drivers enabled - which is what setup() used
  // to write directly. From here on this task is its only writer.
  pinMode(ELS_STEPPER_ENA, OUTPUT);
  digitalWrite(ELS_STEPPER_ENA, 0);

  // 2 KB is ample: the loop has no recursion, no printf and no locals beyond a
  // pointer and two bools.
  xTaskCreatePinnedToCore(AlarmTask, "Alarm", 2048, nullptr, 2, nullptr, 0);
}

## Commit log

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2026-08-15 Add WiFi captive portal for configuration AP
    When the device is in configuration AP mode, joining the network now shows
    the config page at any URL instead of requiring the user to browse to the
    IP shown on the display.
    - Wildcard DNSServer on port 53 resolves every lookup to the softAP IP
    - OS captive-portal probe endpoints (Android/Apple/Windows) 302-redirect to
    the portal so the "Sign in to network" sheet appears automatically
    - onNotFound serves the portal for any other host/path
    - dnsServer.processNextRequest() serviced in the existing wifiLoop()
    Existing /, /set and /reset routes are registered first and unchanged.
    Needs on-hardware confirmation (native env does not build this web c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
    [WebSettings.cpp]
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2026-08-15 Fix steps-per-mm regression (restore /leadscrewPitchMm divisor)
    LatheConfigDerived::leadscrewStepsPerMm() had dropped the /leadscrewPitchMm
    divisor present in the old ELS_LEADSCREW_STEPS_PER_MM macro, making it return
    motor steps per leadscrew *turn* (800 at defaults) instead of steps per *mm*
    (314.96). This inflated acceleration, jog-speed and max-speed limits ~2.54x
    and shortened the initial pulse delay by the same factor. Thread/feed pitch
    tracking was unaffected (m_ratio uses motorPulsePerRevolution directly).
    - lib/config/latheconfig.cpp: restore the / leadscrewPitchMm() divisor
    - test/test_latheconfig: assert the corrected (pre-websettings) scaling,
    expressed via the same float arit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
    [test_latheconfig.cpp]
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2026-08-15 Fix uninitialized members left by the statics->heap refactor
    Commit b0b6137 converted the global static objects to heap `new` in setup().
    Static storage was zero-initialised; heap memory is not, so members that
    relied on implicit zero-init started with garbage.
    - src/keyarray.cpp: initialise keycodeMillis (and buttonState/readindex/
    writeindex) in the KeyArray constructor. A garbage keycodeMillis made the
    debounce `time < keycodeMillis + 10` in handle() permanently true, so every
    button-matrix press was swallowed (the rotary encoder was unaffected). This
    is the "buttons don't work / can't unlock" regression; last-good was cbd1b22.
    - lib/axis/axis.h: initialise m_lastRev* in Axis();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
    [keyarray.cpp]
2026-08-15 Add reverse-thread mode (Thread down-left-to-right)
    Adds a fourth feed mode, FM_THREAD_REVERSE, in the Mode-button cycle
    (Feed -> Thread -> Thread-reverse -> Jog). It cuts exactly like Thread using
    the same pitch tables, but drives the leadscrew the opposite direction (from
    the left stop toward the right) for left-hand threads / threading away from a
    shoulder.
    Implementation: getCurrentFeedPitch() returns a NEGATED pitch in reverse mode,
    which negates the leadscrew:spindle ratio in setTargetPitchMM(); everything
    else (sync, endstops, feed-select) treats reverse the same as thread. No
    buttonpad change needed (reverse is not Jog, so jog/stop handling is unchanged).
    - lib/global_state/globals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
    [test_leadscrew.cpp]
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2026-08-15 Redesign the web configuration page (mobile-first, validated)
    Replace the plain form with a responsive, grouped, theme-aware config page
    (the approved "Workshop / amber" direction): Network & Updates, Lathe
    Geometry, Motion Limits, with unit adornments, number steppers, a real
    invert-direction toggle, and password show/hide.
    Adds client-side validation that blocks empty / non-integer / <1 values for
    the encoder PPR, stepper PPR and gearbox numerator/denominator (and >0 for
    pitch) before submit — the UX guard against the setValues() std::stoi throw
    and divide-by-zero paths. Field name= attributes are unchanged, so /set,
    /reset and the captive portal keep working; values are server-rendered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
    [WebSettings.cpp]
2026-08-15 Harden setValues() against bad/oversized form input
    Server-side counterpart to the config-page validation, covering the review's
    report-only findings:
    - Replace throwing std::stoi/std::stof with non-throwing parseIntArg/
    parseFloatArg. Empty or non-numeric input now falls back to the field's
    default instead of throwing (which previously aborted/rebooted the ESP32).
    - Clamp every numeric field to a safe minimum (PPR/stepper/gearbox terms and
    speeds >= 1, pitch >= 0.001) so a blank or 0 can never reach the encoder
    modulo or the gearbox/steps-per-mm division and divide by zero.
    - Replace strcpy with a bounded copyArg() so an over-long ssid/password/url
    POST can't overflow the fixed W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
    [WebSettings.cpp]
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2026-08-15 Add thread-helix sync tests; give TestSpindle realistic velocity
    New host suite test_thread_sync proves, for both right-hand and left-hand
    (reverse) threads, that the tool lands on the same helix regardless of spindle
    speed (spindle phase at the sync stop is speed-independent), that the pitch
    matches the configured ratio, and that deceleration parks on the correct
    endstop. Spindle is driven at constant RPM over the virtual clock (300/1200/
    3000 PPS) with fractional-pulse carry.
    TestSpindle now reports a real, time-based velocity mirroring ESPSpindle
    (previously stubbed to 0), so the leadscrew's speed-dependent feed-forward is
    actually exercised. Existing suites remain green (their single-ju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
    [test_thread_sync.cpp]
2026-08-15 Add per-setting coverage tests
    New test_settings suite (17 cases, ~107 assertions) verifies each LatheConfig
    setting propagates correctly and in isolation:
    - Derived values: for every setting, changing it updates exactly the derived
    values that depend on it (per the latheconfig.cpp formulas) and leaves the
    rest byte-identical to default. Covers spindleEncoderPpr, stepperPpr, gearbox
    numerator/denominator, leadscrewPitchMm, jogSpeed, leadscrewAcceleration,
    leadscrewMaxSpeed, invertDirection (2-3 values each).
    - Motion reflection: the ratio inputs (encoder PPR, stepper PPR, gearbox terms,
    pitch) change carriage travel by the expected factor, pinned via the
    invariant "travel per sp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
    [test_settings.cpp]
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2026-08-15 Fix unsetStop spindle-sync re-anchor (test-first)
    When the stop holding the spindle-sync anchor is cleared while the other stop
    is set, unsetStop is meant to move the anchor to that other stop by
    extrapolating the spindle phase across the gap. The old code got this wrong
    four ways: it used the syncPositionState enum ordinal (not spindleSyncPosition)
    as the base, read that enum after reassigning it, computed the stop-gap after
    the source position had already been reset to its INT32 sentinel (overflow),
    and multiplied by ratio instead of dividing (with the wrong delta sign in the
    RIGHT branch). The re-anchored phase was therefore garbage -> a later thread
    pass would pick up on the wrong helix.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
    [test_stopsync.cpp]
2026-08-16 OTA from GitHub Releases with version-skip check
    Move OTA firmware distribution off the home network onto GitHub Releases,
    using the stable latest-asset permalink so the URL never changes:
    https://github.com/<repo>/releases/latest/download/elstft.bin
    - include/version.h: FIRMWARE_VERSION ("v0.1.0"), compared to the release tag.
    - board.h: OTA_GITHUB_REPO / OTA_ASSET_NAME (derive the API + download URLs).
    - ESPCommsManager: replace HttpsOTA with WiFiClientSecure + HTTPClient using the
    arduino-esp32 CA cert bundle (verified symbol _binary_x509_crt_bundle_start
    for core 2.0.17) and HTTPC_STRICT_FOLLOW_REDIRECTS (handles the
    github.com -> *.githubusercontent.com asset redirect). Flow: c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
    [ESPCommsManager.cpp, WebSettings.cpp]
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2026-08-16 FS-B tests: carriage and stop position in mm (failing)
    Test author stage. 12 cases in test_position_mm covering getPositionMM(),
    getStopPositionMM() and getConfig(). Expected values are derived from
    LatheConfigDerived::leadscrewStepsPerMm() rather than hardcoded, so they
    survive a config change.
    Contract for unset stops: getStopPositionMM() returns NAN, and
    getStopPositionState() stays the sole authority for whether a stop is set.
    The INT32_MIN/INT32_MAX pulse sentinels must never be converted to mm.
    leadscrew.h carries wrong-value stubs so the suite links and fails on
    assertions rather than link errors. 10 of 12 fail as intended; the two
    round-trip cases pass spuriously because both stubs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
    [test_position_mm.cpp]
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2026-08-16 FS-D tests: UI focus state machine (failing)
    Test author stage. New pure-C++ lib/ui, host-buildable, holding the focus
    model so the most intricate new logic in the project is testable - it would
    not have been in src/buttonpad.cpp, which the native test runner never
    builds. 67 cases, 54 failing against deliberate stubs.
    The load-bearing discovery is in keyarray.cpp:144-170: a short press emits
    Press then Click then Release, a long press emits Press then Hold then
    Release with no Click. That ordering forces most of the contract - arrows
    must be inert on Click when the stop is unset and inert on Press/Release
    when it is set, or a single tap either double-fires or aborts the run it
    just started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
    [test_uistate.cpp]
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2026-08-17 FS-D review: inhibit stop edits while engaged; fix dead-man jog release
    Reviewer stage. 66 -> 80 cases, all green. Two real hazards closed.
    Stops are now inert while motionEnabled, both arrows, both directions. The
    justification for allowing them does not survive contact with the code:
    hitLeftEndstop() is the SOLE arrest for an engaged feed
    (leadscrew_stopsync.h:98-106, leadscrew.cpp:239), and unsetStop sets the
    position to INT32_MIN, so clearing a stop mid-cut does not move the arrest,
    it deletes it permanently and the carriage feeds into the chuck. Clearing
    the far stop is quieter but re-extrapolates the helix anchor through an
    integer truncation mid-cut, which stays invisible until the n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
    [test_uistate.cpp]
2026-08-17 FS-B review: implementation correct; strengthen the config identity test
    Reviewer stage, 12/12 green. No change needed to leadscrew.h.
    The NAN guard is correct for the right reason rather than by luck: the stop
    state is read as an independent field before getStopPosition() is called at
    all, so a sentinel never reaches the division - the guard does not depend on
    what the sub-call returns for an unset stop.
    Precision checked with real numbers rather than asserted. At ~314.96
    pulses/mm, even an unrealistic 5m bed is ~1.57M pulses, well inside float's
    24-bit exact-integer range of ~16.8M (about 53m of travel). Worst-case
    absolute error there is ~0.0006mm against a display precision of 0.01mm
    m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
    [test_position_mm.cpp]
2026-08-17 FS-F tests: theme and DRO datum config fields (16/16)
    Test author stage. Two uint8_t fields appended to LatheConfig, deliberately
    at the end: this is a flash layout, not just an in-memory one, so adding
    trailing bytes extends the existing trailing pad without moving any existing
    member's offset. Plain uint8_t rather than enum class, which has no
    guaranteed underlying size across compilers and optimisation levels.
    CHECKVALUE bumped to 0xDFEB0941, with a test asserting it differs from the
    old value. That guard is the point: a stored blob written by older firmware
    is now shorter than sizeof(LatheConfig), so the new bytes would read back as
    whatever flash garbage followed them. The bump forces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
    [test_latheconfig.cpp]
2026-08-17 FS-D2 tests: motionActive gating and run reconciliation (5 failing)
    Test author stage for the two hazards the FS-D review found but could not
    reach from its own scope. 80 -> 90 cases, 5 failing.
    Adds bool motionActive to UiContext - "the carriage is under power right
    now", true for an engaged feed, a powered run-to-stop, an interactive jog or
    deceleration. motionEnabled keeps its narrower MM_ENABLED meaning, and that
    gap is the bug: a run-to-stop is MM_JOG_LEFT/RIGHT, so the existing inhibit
    was false for the entire duration of a run. Three ordinary presses could
    clear the stop the carriage was travelling toward under power, and since
    that stop is the run's only arrest, the run would never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
    [test_uistate.cpp]
2026-08-17 FS-J: RTC-memory boot-to-setup flag
    There is currently no runtime path into config mode - runWifiSettings() is
    file-local and reachable only by holding the half-nut key at power-on or by
    failing CHECKVALUE. This adds a third way in for the Setup menu tile.
    RTC_DATA_ATTR rather than flash: WebSettings and LatheConfig share one 4KB
    sector erased as a unit, so a flash boot flag would put the wifi credentials
    at risk on every use and burn wear for a one-shot signal. RTC slow memory
    survives ESP.restart() and clears on a true power cycle, which is exactly
    the lifetime wanted.
    The magic is 0xE15B0071, deliberately not 0 or 0xFFFFFFFF - RTC memory is
    not guaranteed zeroed on cold boot and those a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
    [main.cpp]
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2026-08-17 FS-F: implement saveLatheSettings(); const-correct the derived config
    Two jobs.
    saveLatheSettings() re-reads WebSettings from flash BEFORE erasing, then
    erases the shared 4KB sector once and writes both structs back. That
    ordering is the whole point: the wifi credentials and the lathe config live
    in one sector erased as a unit, so saving a theme toggle without preserving
    WebSettings first would wipe the network setup. Follows the existing
    setValues() pattern. Null config is rejected before touching flash, and the
    owned pointer from getWebSettings() is deleted rather than repeating the
    known leak at main.cpp:124.
    NOT verified. The native runner never builds src/, and flashRead/
    flashEraseSe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
    [WebSettings.cpp]
2026-08-17 FS-D2 review: replace the packed latch with a phase enum (92/92)
    Reviewer stage. The direction really was write-only state - every reference
    tested != 0, the cancel is direction-blind by construction and pinned as
    such, and the intent is chosen from the key in hand rather than the member.
    So m_runToStopDir becomes RunPhase { None, Commanded, Confirmed } and the
    sign packing goes. All 90 existing cases passed unmodified, which is the
    evidence the refactor changed no behaviour.
    The interaction I was most worried about turns out to be structurally
    blocked rather than merely unlikely: a jog can only start below the latch's
    early return, so an in-flight jog and a live latch cannot coexist and no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
    [test_uistate.cpp]
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2026-08-17 FS-G review: verify intent fidelity; correct two wrong comments
    Reviewer stage, 210/210. The mapping is faithful - the two things most
    likely to break silently both survived intact.
    SS_UNSYNC was set in exactly two places in the old handlers, the click-to-run
    path and the FM_JOG press path, and both survive with the same ordering. No
    stale thread anchor can outlive a jog. setTargetPitchMM is called after every
    surviving pitch or mode change, and ModePrev correctly adds a fifth call
    site; the only absent one belonged to the deleted unit toggle. Nothing
    leaves the leadscrew on a stale ratio.
    Both judgement calls confirmed with evidence rather than agreement. The
    drain is hard-bounded at ten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
    [buttonpad.cpp]
2026-08-17 Delete the dead discrete-button branch in setup()
    Found by the FS-G review. The #else of ELS_USE_BUTTON_ARRAY configured nine
    GPIOs from ELS_*_BUTTON names that no longer exist, and the macro is defined
    unconditionally in board.h so the branch has not compiled in a long time.
    Worse than merely dead: after the Mk2 remap those names are matrix codes
    rather than GPIO numbers, so ELS_ENABLE_BUTTON would still have resolved and
    quietly configured the wrong pin for anyone who re-enabled it. There is no
    discrete-button hardware left to support.
    [main.cpp]
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2026-08-17 FS-E tests: thread sync point (12 of 13 failing)
    Test author stage for the only genuinely new motion behaviour in the
    redesign - anchoring the helix to the current spindle angle and carriage
    position so an existing thread can be picked up.
    setSyncPoint() takes no parameters deliberately. It is called from the
    DisplayTask while the SpindleTask is inside update(), so a caller passing
    (carriagePos, spindlePhase) could sample the two coordinates at different
    instants and anchor a skewed pair - a half-pitch error you would only
    discover in steel. Taking both itself, in one call, makes a skewed anchor
    unrepresentable.
    The suite uses 1.27mm pitch rather than the existing suite's 0.25 because it
    g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
    [test_sync_point.cpp]
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2026-08-17 FS-E review: fix a carriage lurch on sync; close a reverse-thread hole
    Reviewer stage, 15/15 and the full suite at 225/225.
    The critical defect, which no existing test caught: setSyncPoint() raised
    SS_SYNC unconditionally, and raising SS_SYNC is exactly what RELEASES the
    re-sync gate. While that gate holds the axis, update() keeps accumulating
    spindle motion into m_expectedPosition with m_currentPosition frozen, so the
    following error grows by a whole pitch per revolution of holding. Firing the
    gate normally is what discards that accumulation; jumping it skipped the
    discard and handed the axis a large error to close at maximum speed.
    Measured on the host rig, a sync taken a quarter-revoluti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
    [test_sync_point.cpp]
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2026-08-17 FS-I3a: the four selector overlays
    MODE, RATE, JOG SPEED and STOPS, drawn as one panel whose content groups
    swap by focus rather than four separate panels. Solid fill with a 2px accent
    border - translucency is impossible here, since layer opacity would need
    ~84KB against a 24KB budget. Hidden via a flag rather than deleted, so the
    10Hz tick does not rebuild it.
    Display can now see the focus state: ButtonPad already exposed a const
    UiState&, and both run on the DisplayTask, so this is a same-task read
    needing no volatile and no GlobalState round trip. It does mean ButtonPad
    must be constructed before Display, which main.cpp already did and now says
    so.
    The pitch formatting was extracted rat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
    [main.cpp]
2026-08-17 FS-I3b: menu carousel and tile actions
    Restores three capabilities that this branch had made unreachable: OTA
    updates, the metric/imperial toggle, and display reset. Their old key
    gestures went with the keys they lived on; this menu was always their
    designed home.
    The tile order is defined once, as an enum in the display header, with a
    static_assert tying it to UiState::kMenuItemCount. Beside it sits one
    availability rule both sides call - the display dims and explains, the
    buttonpad refuses - so they cannot disagree about whether a tile is live.
    All the interaction itself stays in UiState, which already has 92 host tests
    behind it; the display only renders what it reports.
    Three gates enf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
    [buttonpad.cpp]
2026-08-17 Move the menu availability rule into lib/ui so it can be tested
    menuTileBlock() decides whether Sync, Software update, Wi-Fi setup, Theme
    and DRO datum are allowed to fire - the gates that stop a settings save
    stalling the spindle loop mid-cut, and stop a sync lurching the carriage
    into the work. It lived in lib/display behind <lvgl.h>, which the native
    runner cannot build, so the most safety-relevant new function on the branch
    had zero coverage while the interaction model beside it had 92 cases.
    Moved to lib/ui/uistate.h, which is pure C++ and already host-tested. The
    signature was already platform-free, so this is a pure relocation with no
    behaviour change. Both call sites still call the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
    [buttonpad.cpp, test_uistate.cpp]
2026-08-17 Cover the re-sync gate after an endstop arrest (3 tests)
    Investigation into a suspected safety hole. Verdict: the leak does not
    occur, and no production code changed - but both sides of the argument were
    wrong in ways worth pinning.
    The claim was that after an arrest the commanded mode reads MM_DISABLED
    while update() keeps accumulating error behind a held gate, so a menu Sync
    would render live and lurch the carriage. Its caveat was "unless the
    deceleration planner always lands on exactly zero speed". That caveat is
    false: measured residual speed is 0 at 300 PPS but 6.9 at 1200 and 142.5 at
    3000, at the same 0.25mm pitch. The accumulation is real.
    What saves it is that the re-sync SEARCH r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
    [test_thread_sync.cpp]
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2026-08-17 Run the leadscrew speed down while the re-sync gate holds
    Stopping the lathe right after an endstop arrest left m_leadscrewSpeed
    frozen at its arrest value indefinitely - measured 6.9 to 309.8 PPS still
    present after 20s of idle. The gate's short-circuit return skips
    sendPulse(), which was the only place the speed decayed.
    The fix reuses the planner's own law rather than inventing a second one. The
    deceleration step - one decrement of accel times dt, paced at the pulse
    interval - is factored out of sendPulse() into decelerationStep() and called
    from the gated path too. That path has already passed the same
    pulse-interval test, so it runs the same decrement at the same cadence; the
    ramp keep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
    [test_thread_sync.cpp]
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2026-08-17 Geometry is web-only: save preferences by value, never by struct
    saveLatheSettings(LatheConfig*) is replaced by
    bool readLathePreferences(uint8_t& theme, DroDatumPreference& droDatum);
    bool saveLathePreferences(uint8_t theme, DroDatumPreference droDatum);
    No caller can pass geometry because no parameter can carry it. Geometry now
    exists only as bytes read back from flash INSIDE the save, and never crosses
    the boundary in either direction - so adding a field to LatheConfig cannot
    silently widen the API, which is precisely what a sizeof-shaped write did.
    That kills three logged defects rather than fixing them. The old path
    reconstructed all nine geometry fields in RAM from the derived c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
    [WebSettings.cpp, buttonpad.cpp, test_latheconfig.cpp]
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2026-08-17 Encoder through focus, clear-both-stops, two-press ENABLE
    All three decisions live in lib/ui, where they are testable; src/ only
    translates and executes. Suite 256 -> 301, test_uistate 106 -> 151.
    The encoder now routes through UiState like every key. One Click per detent,
    since a detent is instantaneous and has no Press/Release to pair. At rest it
    drives PITCH - deliberately not what the arrows do there - so pitch is
    adjustable without pressing RATE first, and it is inert in STOPS because a
    knob is far easier to nudge than a key and committing an endstop must stay a
    deliberate keypress. KeyArray no longer touches GlobalState or Leadscrew at
    all; it just accumulates detents for ButtonPad to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
    [buttonpad.cpp, keyarray.cpp, test_uistate.cpp]
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2026-08-17 Anchor source on Diagnostics; theme the Wi-Fi screens
    Diagnostics now shows where the helix anchor came from - L stop, R stop,
    manual or none - beside the sync chip. GlobalThreadSyncState only says
    synced or not, so without the source a thread that will pick up and one that
    will not look identical on screen. That is precisely what you want to know
    when a recut goes wrong. The exit hint moved up to the title row's empty
    half to make room; the two could not share a row, which is asserted rather
    than assumed.
    The Wi-Fi screens were the first thing anyone sees on a new device and
    looked like a different product - black on LVGL's stock white, because they
    predate the palette and never call init(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
    [scenes.cpp]
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
